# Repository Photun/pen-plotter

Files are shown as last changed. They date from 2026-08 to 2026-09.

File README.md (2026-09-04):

# CoreXY Pen Plotter

A large format Arduino based CoreXY pen plotter with a custom slicer app for turning digital artwork into physical drawings.

## Why This Exists

I intialliy built this beucase I got tired of having to hand trace digital drawings onto paper for art projects, and I wanted to build something that could not only accomodate large poster sizes but also do it with much more precision. So thats why I built this large CoreXY Plotter. I've seen a lot of plotters out there, but none are as big as what I've designed, nor are they as cheap as mine. Mine doens't use large expensive linear rails or flexible rods, but instead it uses rollers to utilize extrusions as the strong gantry while having customizeable sizes. It is mostly 3D printed parts or common hardware parts, no rare or expensive parts. It's rigidity allows it to draw even large desgisn with high precision and repeatability. It can accomodate both pen or pencil, so with more complex code it could probably imitate human handwriting, though obviously not 100%. The design is very human. 

## Photos And Demo

Main project photo:

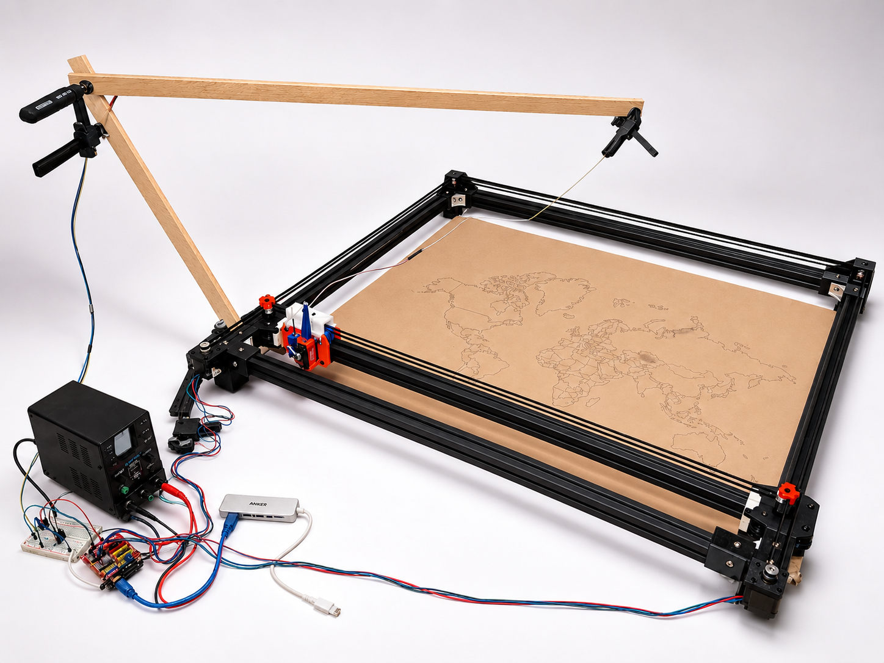
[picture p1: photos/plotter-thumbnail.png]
CoreXY pen plotter


Demo video:

[Plotter running demo video](photos/demo-plotter-running.mp4)

## What It Does

This project is meant to make large physical line drawings from normal digital
artwork without needing a commercial plotter or a bunch of expensive motion
hardware. The machine can be used on large poster sized paper, but can also be
configured to only draw on a mapped smaller size paper through the application.

The custom Plotter Studio app is the brain of the whole plotter. It allows you to import SVGs
or trace raster images, preview and adjust your drawing, then slice the plate into gcode
 and send it directly to the Arduino over USB. The device tab also replaces the usual pile of terminal commands with buttons for connection, manual homing, jogging, pen control, live
speed/accel tuning, job progress, and a small live job map.

The firmware is intentionally simple enough to run on an Arduino Uno, but still
handles the plotter's key features: CoreXY motor conversion, absolute gcode
movement, manual home confirmation, trapezoid style acceleration, task interjection,
servo pen up/down timing, and MOSFET controlled servo power to avoid the
boot twitch problem.

## How It Fits Together

The hardware is the large CoreXY frame, rollers, belts, gantry, and pen toolhead. 
The firmware is the real time layer that turns gcode into step pulses and pen movements. 
Plotter Studio is the computer side layer that turns art into motor instructions from user input.
The user imports art, fits it to the selected drawing area, generates gcode, provides the 
preview, and streams it to the Uno firmware.

## Build One

Start with the hardware docs:

- [Assembly guide](hardware/assembly.md)
- [Bill of materials](hardware/bom.md)
- Printable STL files in [hardware/exports/stl](hardware/exports/stl)
- Printable STEP files in [hardware/exports/step](hardware/exports/step)
- Full assembly STEP file in [hardware/exports/assembly](hardware/exports/assembly)

The CAD is also available in Onshape:

```text
https://cad.onshape.com/documents/21408afa0678dfc090a39137/w/cada99e8b20e026a88815622/e/614e2d6018b77ddf107765d2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
```

After the hardware is assembled and wired, use
[Plotter Studio instructions](firmware/instructions.md) to upload the Arduino
firmware, launch the app, run first motion tests, align letter paper, import art,
slice the plate, and send drawings. The deeper firmware/app notes are in
[firmware/technical-notes.md](firmware/technical-notes.md).

## Repo Layout

```text
hardware/            assembly guide, BOM, exported CAD/STL files
firmware/            Arduino firmware, Plotter Studio app, scripts, examples
photos/              sample plots, wiring photos, demo video
```

Most readers should start with this README, then `hardware/assembly.md`, then
`hardware/bom.md`. The firmware internals are mostly for people changing code.

Generated local folders such as `.pio/`, `.venv/`, `.plotter-app/`, and
`Plotter Studio.app/` are not part of the source package.

## What I Would Do Differently

The biggest thing I would rethink is tolerance. This project made it really
obvious that CAD numbers and printed numbers are not the same thing, especially
with ABS. Warping can change dimensions enough that one part is too tight while
another part is too loose, even when they were designed with the same logic. The
toolhead is a little loose in some places, and that costs rigidity, which then
costs drawing precision.

The rollers also showed this problem. Some spin smoothly, some are too tight,
and some basically drag instead of rolling. After seeing the actual prints, I
started wondering if a sliding plastic block in the extrusion groove might have
been better than round rollers. A roller only touches at a tangent point, while a
printed rectangular slider could contact the extrusion in a more constrained and
repeatable way. It might even be more precise, as long as the friction is
manageable.

The belt clamp mount is another place where I designed the part first and
thought about assembly second. It works, but it was one of the hardest parts to
put together. If I rebuilt it, I would probably design more of that toolhead area
as one piece instead of splitting it into pieces just to avoid supports. I did
not trust support structures that much while designing this, but after printing
more parts, I am a lot more willing to use supports for harder shapes if it makes
the final assembly simpler and stiffer.

## License

This project is licensed under the MIT License. See `LICENSE`.

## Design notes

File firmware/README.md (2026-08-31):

# Firmware And Plotter Studio

This folder contains the Arduino firmware, the Plotter Studio app, and the small
helper scripts used to run the machine.

Start here:

- [Instructions](instructions.md) for normal use: opening art,
  slicing, connecting, homing, tuning, and sending a plot.
- [Technical notes](technical-notes.md) for how the app, slicer, serial sender,
  gcode, motion planner, and servo power system fit together.

Most users should not need to touch the Python scripts directly. Normal drawing
happens through Plotter Studio, while firmware only needs to be re-uploaded when
`src/main.cpp` changes.

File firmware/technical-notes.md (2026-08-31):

# Technical Notes

This file describes how the software side works. It is not the main user guide;
it is here so the firmware, slicer, and serial behavior are easier to understand
or modify later.

## System Shape

The plotter has three main software pieces:

```text
src/main.cpp                 Arduino Uno firmware
tools/plotter_studio.py      local Python backend and serial controller
app/static/*                 Plotter Studio frontend
```

The Mac app in `desktop/macos/` is a small WebKit wrapper. It starts the Python
backend and loads the local Plotter Studio page. The generated `Plotter
Studio.app` is intentionally ignored by git because it is a local build artifact.

## Firmware Target

```text
board: Arduino Uno
shield: CNC Shield V3
drivers: DRV8825
baud: 115200
machine area: X406 Y370
```

Pin mapping:

```text
D2   CNC Shield X step = CoreXY motor A step
D3   CNC Shield Y step = CoreXY motor B step
D5   CNC Shield X dir  = CoreXY motor A dir
D6   CNC Shield Y dir  = CoreXY motor B dir
D8   CNC Shield enable, active LOW
D11  Z-limit signal -> servo power MOSFET gate
D12  SpnEn -> servo signal
```

The machine coordinates are internal plotter units, not real millimeters. That
is why the full area is `406 x 370`, while Letter paper is represented as `140 x
108.182` in the app.

## Serial Protocol

The firmware reads newline-terminated serial commands at `115200` baud. Most
commands reply with `ok` when complete or `error` when rejected. The Python
backend sends one command at a time and waits for the acknowledgement before
sending the next normal gcode line.

There is also a realtime abort byte so `Stop` can interrupt long moves without
waiting for the current line to finish. After aborting, the app lifts the pen,
returns to `X0 Y0` when home is confirmed, and resets job state.

Manual serial commands:

```text
?                 show help
h                 confirm current position as X0 Y0
p                 print position/settings
mon / moff        enable / disable motors
u / d             pen up / pen down
son / soff        servo power on / off
a 100             set servo angle directly
s 20              set raw step delay
accel 20000       set raw acceleration
```

Supported plot-style commands:

```text
G0 Xn Yn Fn       travel move
G1 Xn Yn Fn       draw move
G5 Xn Yn I J P Q  cubic bezier move
G28 P1            confirm manual home at X0 Y0
M3                pen down
M5                pen up
M17 / M18         motors on / off
M204 Snnn         acceleration in steps/sec^2
M340 U D L        pen up wait, pen down wait, lift percent
M2 / M30          end program, pen up and servo off
```

## Motion Planning

The firmware uses CoreXY mixing, so Cartesian X/Y moves are converted into motor
A/B step counts. The movement loop steps whichever motor axes need a pulse at
each Bresenham-like interval so straight lines stay coordinated.

Speed is controlled mainly by step delay. Lower delay means faster pulses.
Acceleration controls how quickly the firmware is allowed to approach that
requested speed. The intended velocity profile is trapezoidal: accelerate,
cruise when the line is long enough, then decelerate. For short moves, the
profile naturally becomes triangular because there is not enough distance to hit
the requested top speed.

Curves are not sent as hundreds of tiny straight gcode segments when the slicer
can preserve them. The app can emit cubic bezier moves as `G5`, and the firmware
samples those curves internally while sharing one continuous motion profile
across the curve. This avoids the repeated stop/start behavior that happens when
a curve is broken into too many independent line moves.

## Servo Power And Pen Lift

The pen servo is powered through a low-side MOSFET so it does not twitch at boot.
The firmware sets the desired servo target, attaches the servo signal, then turns
on the MOSFET-controlled power. When powering off, it lifts the pen first, cuts
power, waits briefly, then detaches the servo signal.

Wiring summary:

```text
Servo red wire       -> external 5V +
Servo brown/black    -> MOSFET drain
MOSFET source        -> external 5V GND and Arduino/CNC shield GND
Servo orange/yellow  -> CNC shield SpnEn / D12 signal
D11 / Z-limit signal -> 220 ohm resistor -> MOSFET gate
MOSFET gate          -> 10k pulldown -> GND
```

All grounds must be common.

The app exposes pen up wait, pen down wait, and pen up lift percent. The lift
percent is useful for dense dotted drawings where the pen only needs to rise a
little before the next nearby stroke.

## Slicing Pipeline

Plotter Studio accepts SVG directly and raster images through the trace importer.
SVG paths are parsed with `svgpathtools`. Lines, quadratic curves, cubic curves,
and arcs are normalized into drawable strokes. The slicer keeps cubic geometry
where possible so the firmware can run smoother bezier motion.

Raster tracing uses OpenCV-based preprocessing and contour extraction. The import
settings control how aggressively edges are found, simplified, linked, and
filtered. Tracing runs as a cancellable job: changing a setting abandons the old
trace request so a bad threshold does not trap the app in a long computation.

Before gcode is accepted, the backend checks machine bounds, selected paper
bounds, and margin warnings. Outside the machine or selected paper blocks
slicing. Inside the paper margin only warns.

After slicing, the generated preview contains path geometry, gcode text, bounds,
warnings, estimated distance, and estimated runtime. Confirming the slice queues
that result for the Device tab.

## Route Optimization

The slicer groups drawable geometry into strokes and orders them to reduce
pen-up travel. It can reverse strokes when starting from the other end is
shorter. This is a practical nearest-neighbor style optimization, not a perfect
traveling-salesman solve. The goal is to cut obvious wasted travel without
making slicing painfully slow.

This matters because every pen-up travel and every separate stroke resets some
motion momentum. Fewer disconnected strokes usually means less servo waiting,
less acceleration/deceleration, and a cleaner plot.

## Generated And Ignored Files

These are local artifacts and should not be committed:

```text
.pio/
.venv/
.plotter-app/
Plotter Studio.app/
```

The source files live in git. The built app, Python environment, PlatformIO
builds, uploaded images, and local logs are regenerated on each machine.

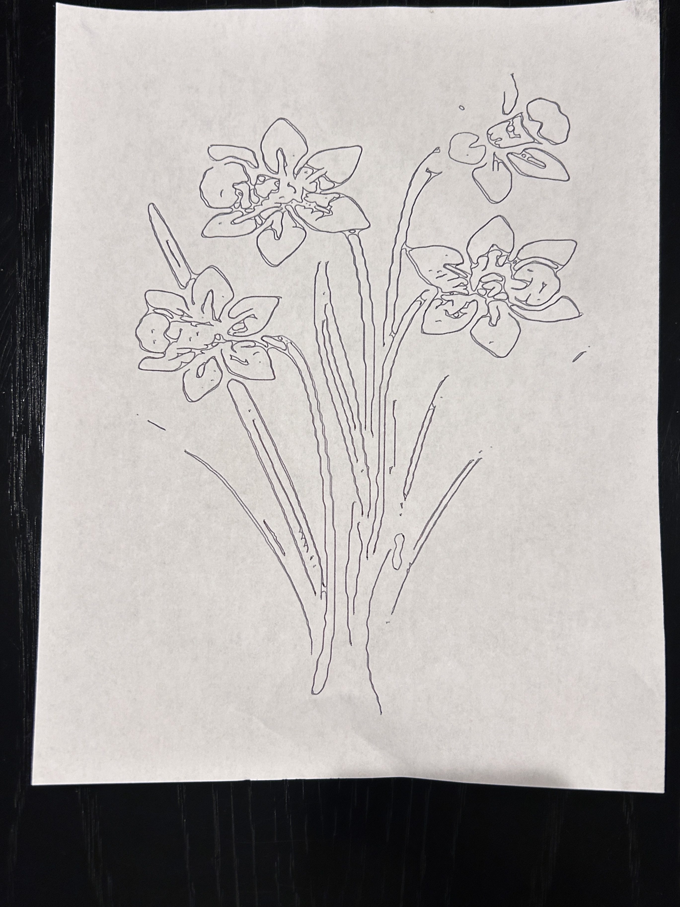
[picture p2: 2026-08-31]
photos/sample-plot-flowers.jpg

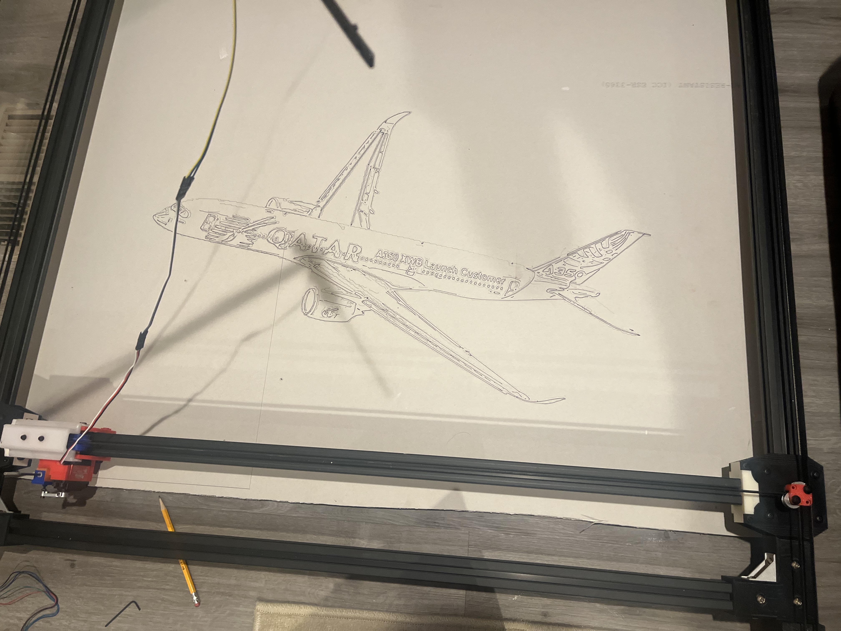
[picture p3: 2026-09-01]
photos/sample-plot-airplane.jpg

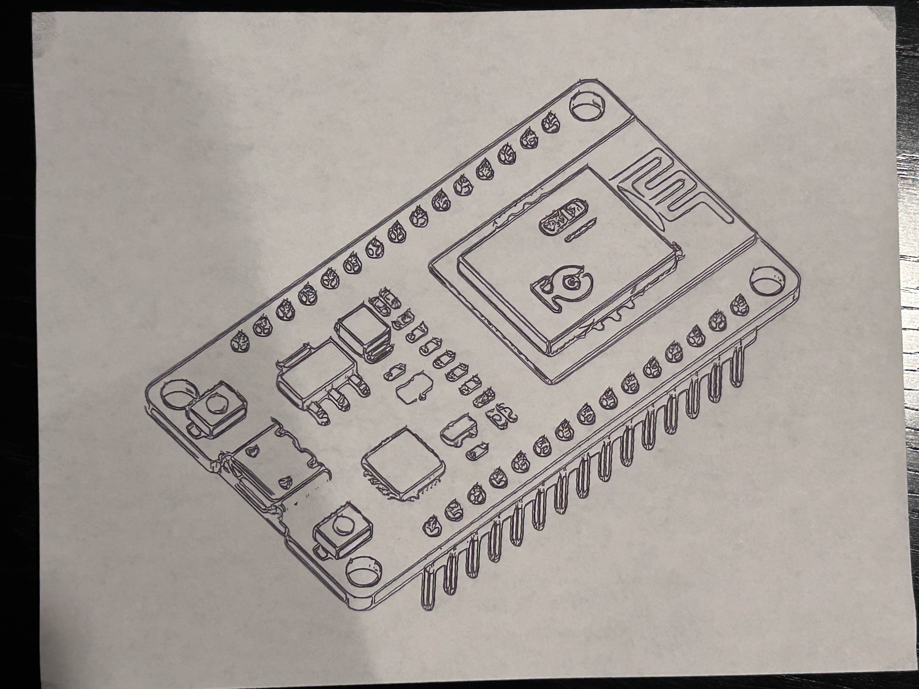
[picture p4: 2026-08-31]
photos/sample-plot-esp32-board.jpg

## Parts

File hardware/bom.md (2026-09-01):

# Bill of Materials

This BOM is split into purchase groups and itemized build parts. Some rows in
the machine are bought together, so the price belongs to the kit/link, not every
individual part inside it.

Prices are pulled from the linked listings when available, but should still be
checked before ordering because Amazon prices move around.

## Purchase Groups

| ID | Buy / source | Price | Notes |
| --- | --- | ---: | --- |
| P01 | [DAOKI CNC Shield V3.0 kit](https://www.amazon.com/dp/B08KFYKKN4) | $9.99 | Includes Arduino-compatible Uno, CNC Shield V3, 4 DRV8825 drivers, heatsinks, jumper caps, and USB cable. |
| P02 | [STEPPERONLINE NEMA 17 stepper motor, 3-pack](https://www.amazon.com/dp/B0B38GHRH8) | $10.19 | Build uses 2 motors; this listing includes 3. |
| P03 | [ANNIMOS 20kg metal gear servo](https://www.amazon.com/dp/B0769DFJVK) | $14.99 | Pen lift servo. |
| P04 | [GT2 belt, pulley, idler, tensioner, and clamp kit](https://www.amazon.com/dp/B0D2XXF6H7) | $14.99 each | Buy 2. Each kit has 5m of 6mm GT2 belt, 20T pulleys, idlers, tensioner springs, clamp blocks, and wrench. |
| P05 | [uxcell 625ZZ bearings, 25-pack](https://www.amazon.com/dp/B0CJFRSK7D) | $7.89 | Build uses 24 bearings. |
| P06 | [3030 aluminum extrusion, 39.4 inch, 10-pack](https://www.amazon.com/dp/B0C9WGJNR9) | $46.99 | Cut into the frame and gantry pieces. |
| P07 | [3030 corner bracket + M6 T-nut connector kit](https://www.amazon.com/dp/B0B12FJRQ3) | Check listing | Includes 3030 corner brackets, M6 T-nuts, M6 x 12 bolts, and wrench. |
| P08 | [M3 screw/nut/washer assortment](https://www.amazon.com/dp/B0FGV5FCBN) | $9.99 | Small toolhead, cart, servo, and motor hardware. |
| P09 | [M4 screw/nut/washer assortment](https://www.amazon.com/dp/B0DD79T1CW) | $9.99 | Belt clamp hardware. |
| P10 | [M5 screw/nut/washer assortment](https://www.amazon.com/dp/B0CSY7FMQD) | $9.99 | Roller and pulley stack hardware. |
| P11 | [M6 screw/nut/washer assortment](https://www.amazon.com/dp/B0GHM7GBXF) | $9.99 | Optional/extra M6 hardware. The connector kit already includes the main M6 x 12 frame bolts. |
| P12 | [IRLZ44N logic-level N-channel MOSFET](https://www.amazon.com/IRLZ44N-IRLZ44NPBF-Mosfet-N-Channel-0-02Ohm/dp/B09SV14RX7) | Check listing | Servo anti-twitch power switch. |
| P13 | [Aluminum cutting blade and paraffin wax](https://www.amazon.com/s?k=aluminum+cutting+blade+paraffin+wax) | Check listing | Optional extrusion cutting helpers. |
| A01 | Assumed project supplies | Already owned | Breadboard, 220 ohm resistor, 10k ohm resistor, bench power supply, external 5V source, pen/pencil, spring, zip tie, and jumper wires. |

## Itemized Purchased Parts

| Part | Qty. used | Source group | Notes |
| --- | ---: | --- | --- |
| Arduino Uno-compatible board | 1 | P01 | Included in the electronics kit. |
| CNC Shield V3 | 1 | P01 | Plugs into the Uno. |
| DRV8825 motor driver | 2 | P01 | Kit includes 4; this build uses 2. Set current limit to about 0.45-0.5A. |
| Arduino USB cable | 1 | P01 | Included in the electronics kit. |
| 20kg servo | 1 | P03 | Pen lift servo. |
| Servo horn | 1 | P03 | Use the servo's included horn. |
| NEMA 17 stepper motor | 2 | P02 | CoreXY motor A and motor B. |
| GT2 timing belt | 2x 5m | P04 | Buy 2 kits so each motor gets its own 5m belt. |
| GT2 20T drive pulley, 6mm belt width | 2 | P04 | Mounted to the two stepper shafts. |
| GT2 idler pulley | 8 | P04 | Build uses 6 toothed-style idlers and 2 toothless/smooth-style idlers. Confirm the exact pulley style in the kit before ordering. |
| GT2 aluminum timing belt clamp | 2 | P04 | Included with the GT2 kit. Mounted to the printed belt clamp mount. |
| 625 bearing | 24 | P05 | Used in rollers and bearing stacks. |
| 3030 aluminum extrusion, length pieces | 2 | P06 | 1m pieces before cutting. |
| 3030 aluminum extrusion, width pieces | 2 | P06 | 1m pieces before cutting. |
| 3030 aluminum extrusion, gantry piece | 1 | P06 | Cut from extrusion stock. Use the gantry jig or cut off 58.2mm. |
| 3030 T-nut | 30 | P07 | Use one with each M6 x 12 frame bolt. Gantry extrusion mount ones are optional and not counted. |
| Extrusion bracket | 4 | P07 | Metal brackets for frame corners. |
| M6 x 12 bolt | 30 | P07 | Used wherever a T-nut is used. |
| M6 x 30 bolt | 4 | P11 | Optional if additional gantry-to-cart T-nuts are not desired. |
| M6 washer | 4 | P11 | Optional, used with M6 x 30. |
| M5 x 45 bolt | 8 | P10 | Back corner brackets, bottom of toolhead cart, and Y-cart pulleys. |
| M5 x 50 bolt | 10 | P10 | Y-cart rollers and upper rollers of the toolhead. |
| M5 nut | 18 | P10 | On cart bottoms and roller stacks. |
| M5 washer | 18 | P10 | Used with M5 roller hardware. |
| M4 x 12 bolt | 2 | P09 | Secures belt clamp onto belt clamp mount. |
| M4 nut | 2 | P09 | Behind belt clamp mount. |
| M4 washer | 2 | P09 | Behind belt clamp. |
| M3 x 6 bolt | 1 | P08 | Pencil block pencil clamp. |
| M3 x 10 bolt | 10 | P08 | Stepper motors and belt clamp mount. |
| M3 x 16 bolt | 9 | P08 | Servo/toolhead hardware; 8 rigidity screws are optional. |
| M3 x 25 bolt | 4 | P08 | Y carts for securing upper mold. Optional. |
| M3 nut | 4 | P08 | Two embedded in belt mount, two on M3 x 16 servo mount. |
| M3 washer | 18 | P08 | Small fastener washers. |
| Breadboard | 1 | A01 | Easier interface for servo/MOSFET wiring. |
| Jumper wires | about 40 M-F, about 3 M-M | A01 | Servo power circuit and CNC shield to breadboard wiring. Mostly long male-to-female wires. |
| IRLZ44N logic-level N-channel MOSFET | 1 | P12 | Switches servo ground/power to prevent boot twitch. Logic-level equivalent is okay. |
| 220 ohm resistor | 1 | A01 | Between D11/Z-limit signal and MOSFET gate. |
| 10k ohm resistor | 1 | A01 | Gate pulldown to ground. |
| External 5V power source | 1 | A01 | Powers servo through breadboard rails. |
| 12V bench power supply | 1 | A01 | Powers the CNC shield/motors. Set current low at first during testing. |
| Pen or pencil | 1 | A01 | For pens, remove the ink cartridge and use the pen adapter. |
| Spring for pencil mount | 1 | A01 | OD less than 12mm, height around 30mm. |
| Zip tie | 1 | A01 | 4 inch zip tie for securing servo wire onto aligner. |
| Aluminum cutting blade | optional | P13 | Optional, cleaner extrusion cuts. Prefer negative-angle TCG for nonferrous aluminum. |
| Paraffin wax block | optional | P13 | Optional cutting helper for extrusion. |

## Printed Parts

These parts require PLA, ABS, and PETG filament. The table lists the material
for each part, but no specific filament brand is required.

| Part | Qty. | Material | STL | STEP |
| --- | ---: | --- | --- | --- |
| 0.5 mm Spacer for Y Cart | 2 | PLA | [STL](exports/stl/0.5-mm-Spacer-for-Y-Cart.stl) | [STEP](exports/step/0.5-mm-Spacer-for-Y-Cart.step) |
| 1 mm Spacer for Y Cart | 6 | PLA | [STL](exports/stl/1-mm-Spacer-for-Y-Cart.stl) | [STEP](exports/step/1-mm-Spacer-for-Y-Cart.step) |
| 1.5 mm M+U Spacer for Corner Brackets | 4 | PLA | [STL](exports/stl/1.5-mm-M-U-Spacer-for-Corner-Brackets.stl) | [STEP](exports/step/1.5-mm-M+U-Spacer-for-Corner-Brackets.step) |
| 7.25 mm L Spacer for Corner Brackets | 2 | PLA | [STL](exports/stl/7.25-mm-L-Spacer-for-Corner-Brackets.stl) | [STEP](exports/step/7.25-mm-L-Spacer-for-Corner-Brackets.step) |
| Back Corner Brackets | 2 | ABS | [STL](exports/stl/Back-Corner-Brackets.stl) | [STEP](exports/step/Back-Corner-Brackets.step) |
| Bearing-to-Bearing Internal Roller Spacer | 12 | PLA | [STL](exports/stl/Bearing-to-Bearing-Internal-Roller-Spacer.stl) | [STEP](exports/step/Bearing-to-Bearing-Internal-Roller-Spacer.step) |
| Belt Clamp Mount | 1 | ABS | [STL](exports/stl/Belt-Clamp-Mount.stl) | [STEP](exports/step/Belt-Clamp-Mount.step) |
| Cart Cart Plate | 2 | ABS | [STL](exports/stl/Cart-Cart-Plate.stl) | [STEP](exports/step/Cart-Cart-Plate.step) |
| Cart-to-Bearing Spacer | 24 | PLA | [STL](exports/stl/Cart-to-Bearing-Spacer.stl) | [STEP](exports/step/Cart-to-Bearing-Spacer.step) |
| Gantry Extrusion Jig | 1 | PLA | [STL](exports/stl/Gantry-Extrusion-Jig.stl) | [STEP](exports/step/Gantry-Extrusion-Jig.step) |
| Left Corner Bracket | 1 | ABS | [STL](exports/stl/Left-Corner-Bracket.stl) | [STEP](exports/step/Left-Corner-Bracket.step) |
| Left Lower Cart Plate | 1 | ABS | [STL](exports/stl/Left-Lower-Cart-Plate.stl) | [STEP](exports/step/Left-Lower-Cart-Plate.step) |
| Left Upper Cart Plate | 1 | ABS | [STL](exports/stl/Left-Upper-Cart-Plate.stl) | [STEP](exports/step/Left-Upper-Cart-Plate.step) |
| Left Upper Cart Upper Mold | 1 | ABS | [STL](exports/stl/Left-Upper-Cart-Upper-Mold.stl) | [STEP](exports/step/Left-Upper-Cart-Upper-Mold.step) |
| Modified Surface Roller | 2 | PLA | [STL](exports/stl/Modified-Surface-Roller.stl) | [STEP](exports/step/Modified-Surface-Roller.step) |
| Pen Adapter | optional | PETG | [STL](exports/stl/Pen-Adapter.stl) | [STEP](exports/step/Pen-Adapter.step) |
| Pencil Block | 1 | PLA | [STL](exports/stl/Pencil-Block.stl) | [STEP](exports/step/Pencil-Block.step) |
| Pencil Housing | 1 | PLA | [STL](exports/stl/Pencil-Housing.stl) | [STEP](exports/step/Pencil-Housing.step) |
| Pencil Housing Cap | 1 | PLA | [STL](exports/stl/Pencil-Housing-Cap.stl) | [STEP](exports/step/Pencil-Housing-Cap.step) |
| Right Corner Bracket | 1 | ABS | [STL](exports/stl/Right-Corner-Bracket.stl) | [STEP](exports/step/Right-Corner-Bracket.step) |
| Right Lower Cart Bottom | 1 | ABS | [STL](exports/stl/Right-lower-Cart-Bottom.stl) | [STEP](exports/step/Right-Lower-Cart-Bottom.step) |
| Right Upper Cart Plate | 1 | ABS | [STL](exports/stl/Right-Upper-Cart-Plate.stl) | [STEP](exports/step/Right-Upper-Cart-Plate.step) |
| Right Upper Cart Upper Mold | 1 | ABS | [STL](exports/stl/Right-Upper-Cart-Upper-Mold.stl) | [STEP](exports/step/Right-Upper-Cart-Upper-Mold.step) |
| Servo Wire Aligner | 1 | PLA | [STL](exports/stl/Servo-Wire-Aligner.stl) | [STEP](exports/step/Servo-Wire-Aligner.step) |
| Stepper to Drive Pulley Spacer | 2 | PLA | [STL](exports/stl/Stepper-to-Drive-Pulley-Spacer.stl) | [STEP](exports/step/Stepper-to-Drive-Pulley-Spacer.step) |
| Surface Roller | 10 | ABS | [STL](exports/stl/Surface-Roller.stl) | [STEP](exports/step/Surface-Roller.step) |
| Toolhead Cart Back | 1 | ABS | [STL](exports/stl/Toolhead-Cart-Back.stl) | [STEP](exports/step/Toolhead-Cart-Back.step) |
| Toolhead Cart Connector | 1 | PETG | [STL](exports/stl/Toolhead-Cart-connector.stl) | [STEP](exports/step/Toolhead-Cart-Connector.step) |
| Toolhead Front Cart | 1 | ABS | [STL](exports/stl/Toolhead-Front-Cart.stl) | [STEP](exports/step/Toolhead-Front-Cart.step) |

## Cost Notes

The purchase-group total is only a rough build estimate because many links are
kits, leftovers, or optional tools. If someone already has filament, fasteners,
a power supply, jumper wires, or cutting tools, the real extra cost will be much
lower than buying every source group from scratch.

Using the listed Amazon prices for the main required purchase groups, the build
lands around **$180-$260 USD** if the builder already has common project
supplies like wire, resistors, breadboard, power supplies, basic tools, and
filament. Buying every support item from scratch can push the practical total
closer to **$230-$350 USD**, depending on the exact connector kit, MOSFET pack,
filament rolls, cutting tools, and what hardware assortments the builder already
owns.

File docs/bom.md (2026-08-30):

# Bill of Materials

This is the readable copy of `docs/bom.csv`. The CSV is the spreadsheet-friendly source, and this page is for quickly checking the parts list in the repo.

| Name | Quantity | Material | Description |
| --- | ---: | --- | --- |
| 0.5 mm Spacer for Y Cart | 2 | PLA | Goes on top of the lower pulley on Y carts. |
| 1 mm Spacer for Y Cart | 6 | PLA | Under lower pulley, above and below for upper pulley, on Y cart. |
| 1.5 mm M+U Spacer for Corner Brackets | 4 | PLA | Spacer for the back corner bracket mounts, goes above both idler pulleys. |
| 20kg Servo | 1 | - | - |
| 3030 T nut | 30 | - | Use one with every M6 x 12 nut. Gantry extrusion mount ones are optional. (not counted) |
| 625 Bearing | 24 | - | - |
| 7.25 mm L Spacer for Corner Brackets | 2 | PLA | Bottommost object in the back bracket pulley stack. |
| Aluminum Cutting Blade | - | - | Optional, ideal for cleaner extrusion cuts. Preferably negative angle TCG for nonferrous materials. |
| Arduino Uno + CNC Shield | 1 | - | - |
| Arduino USB cable | 1 | - | - |
| Back Corner Brackets | 2 | ABS | Same for both far side corners. |
| Bearing-to-Bearing Internal Roller Spacer | 12 | PLA | Sandwhiched by bearings inside surface rollers. |
| Belt Clamp Mount | 1 | ABS | Be careful of over tightening the M4 screws onto this. |
| Breadboard | 1 | - | Easier interface for wiring servo. |
| Cart Cart Plate | 2 | ABS | M3x10-16 work for rigidity screws. |
| Cart-to-Bearing Spacer | 24 | PLA | Outside of 625 bearings. |
| Drive Pulley | 2 | - | 6mm GT2 |
| DRV8825 Motor Driver | 2 | - | Set max current to about 0.45 - 0.5. |
| External 5v power source | 1 | - | Plug into rails of breadboard, to power servo. Wiring guide provided. |
| Extrusion Brackets | 4 | - | - |
| Gantry Extrusion | 1 | - | Use gantry jig to cut precisely. Better to cut shorter than leave extra. |
| Gantry Extrusion Jig | 1 | PLA | Optional, or just cut off 58.2 mm |
| GT2 Aluminum Timing Belt Clamp | 2 | - | To be purchased. |
| GT2 Timing Belt | 2x5m | - | One for each motor. |
| IRFZ44N | 1 | - | For preventing servo startup twitch. Wiring guide provided. |
| Jumper Wires | - | - | For cable to servo and some CNC sheild to breadboard wiring. |
| Left Corner Bracket | 1 | ABS | - |
| Left Lower Cart Plate | 1 | ABS | - |
| Left Upper Cart Plate | 1 | ABS | - |
| Left Upper Cart Upper Mold | 1 | ABS | - |
| Length Extrusion | 2 | - | 1 meter |
| M3 nut | 4 | - | 2 more embedded in the belt mount, and 2 on the M3 x 16 on the servo to keep it in place. |
| M3 washer | 18 | - | - |
| M3 x 10 | 10 | - | Holding stepper motors and belt clamp mount onto overarching toolhead block thingy. |
| M3 x 16 | 9 | - | 8 for rigidity are optional. |
| M3 x 25 | 4 | - | On y carts for securing upper mold. *Optional - probably not needded.* |
| M3 x 6 | 1 | - | On pencil block for holding pencil. |
| M4 nut | 2 | - | Behind belt clamp mount |
| M4 washer | 2 | - | Behind belt clamp |
| M4 x 12 | 2 | - | For securing belt clamp onto its mount. |
| M5 nut | 18 | - | On cart bottoms |
| M5 washer | 18 | - | - |
| M5 x 45 | 8 | - | Back corner brackets, bottom of toolhead cart, pulleys of Y carts. |
| M5 x 50 | 10 | - | Roller of Y carts, upper rollers of toolhead. |
| M6 washer | 4 | - | Optional - with the M6 x 30 |
| M6 x 12 | 30 | - | Wherever a T nut is used. |
| M6 x 30 | 4 | - | Optional if additional gantry to cart-cart-plate T nut is not desired. |
| Modified Surface Roller | 2 | PLA | Allows belt to pass through with 0.25 mm clearance. |
| Parrafin Wax Block | - | - | Optional, assists with clean extrusion cuts |
| Pen Adapter | - | PETG | Optional, if using pen. |
| Pen/Pencil | 1 | - | For pens, take out the pen itself from a pen and print the pen adapter to use. |
| Pencil Block | 1 | PLA | - |
| Pencil Housing | 1 | PLA | - |
| Pencil Housing Cap | 1 | PLA | Put spring in before putting on the cap. |
| Power Bench | - | - | 12 volts, 1 amp for everything. Plut into CNC shield's input terminal. |
| Right Corner Bracket | 1 | ABS | - |
| Right lower Cart Bottom | 1 | ABS | - |
| Right Upper Cart Plate | 1 | ABS | - |
| Right Upper Cart Upper Mold | 1 | ABS | - |
| Servo Horn | 1 | - | Use OEM's. |
| Servo Wire Aligner | 1 | PLA | To ensure wire does not wrap or tangle during movement. |
| Spring for Pencil Mount | 1 | - | OD less than 12mm, height around 30mm. |
| Stepper Motor | 2 | - | Nema 17 |
| Stepper to Drive Pulley Spacer | 2 | PLA | On stepper axle, between the motor and the drive pulley. |
| Surface Roller | 10 | ABS | - |
| Toolhead Cart Back | 1 | ABS | - |
| Toolhead Cart connector | 1 | PETG | - |
| Toolhead Front Cart | 1 | ABS | - |
| Toothed Idler Pulley | 6 | - | - |
| Toothless Idler Pulley | 2 | - | For first reverse wind of belt from motor. |
| Width Extrusion | 2 | - | 1 meter |
| Zip Tie | 1 | - | 4" zip ties, for securing servo wire onto aligner. |

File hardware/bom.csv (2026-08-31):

type | id | name | quantity | source_group | price | material | notes | product_link | stl_link | step_link
purchase_group | P01 | DAOKI CNC Shield V3.0 kit |  |  | $9.99 |  | Includes Arduino-compatible Uno, CNC Shield V3, 4 DRV8825 drivers, heatsinks, jumper caps, and USB cable. | https://www.amazon.com/dp/B08KFYKKN4
purchase_group | P02 | STEPPERONLINE NEMA 17 stepper motor, 3-pack |  |  | $10.19 |  | Build uses 2 motors; this listing includes 3. | https://www.amazon.com/dp/B0B38GHRH8
purchase_group | P03 | ANNIMOS 20kg metal gear servo |  |  | $14.99 |  | Pen lift servo. | https://www.amazon.com/dp/B0769DFJVK
purchase_group | P04 | GT2 belt, pulley, idler, tensioner, and clamp kit |  |  | $14.99 each |  | Buy 2. Each kit has 5m of 6mm GT2 belt, 20T pulleys, idlers, tensioner springs, clamp blocks, and wrench. | https://www.amazon.com/dp/B0D2XXF6H7
purchase_group | P05 | uxcell 625ZZ bearings, 25-pack |  |  | $7.89 |  | Build uses 24 bearings. | https://www.amazon.com/dp/B0CJFRSK7D
purchase_group | P06 | 3030 aluminum extrusion, 39.4 inch, 10-pack |  |  | $46.99 |  | Cut into the frame and gantry pieces. | https://www.amazon.com/dp/B0C9WGJNR9
purchase_group | P07 | 3030 corner bracket + M6 T-nut connector kit |  |  | Check listing |  | Includes 3030 corner brackets, M6 T-nuts, M6 x 12 bolts, and wrench. | https://www.amazon.com/dp/B0B12FJRQ3
purchase_group | P08 | M3 screw/nut/washer assortment |  |  | $9.99 |  | Small toolhead, cart, servo, and motor hardware. | https://www.amazon.com/dp/B0FGV5FCBN
purchase_group | P09 | M4 screw/nut/washer assortment |  |  | $9.99 |  | Belt clamp hardware. | https://www.amazon.com/dp/B0DD79T1CW
purchase_group | P10 | M5 screw/nut/washer assortment |  |  | $9.99 |  | Roller and pulley stack hardware. | https://www.amazon.com/dp/B0CSY7FMQD
purchase_group | P11 | M6 screw/nut/washer assortment |  |  | $9.99 |  | Optional/extra M6 hardware. The connector kit already includes the main M6 x 12 frame bolts. | https://www.amazon.com/dp/B0GHM7GBXF
purchase_group | P12 | IRLZ44N logic-level N-channel MOSFET |  |  | Check listing |  | Servo anti-twitch power switch. | https://www.amazon.com/IRLZ44N-IRLZ44NPBF-Mosfet-N-Channel-0-02Ohm/dp/B09SV14RX7
purchase_group | P13 | Aluminum cutting blade and paraffin wax |  |  | Check listing |  | Optional extrusion cutting helpers. | https://www.amazon.com/s?k=aluminum+cutting+blade+paraffin+wax
purchase_group | A01 | Assumed project supplies |  |  | Already owned |  | Breadboard, 220 ohm resistor, 10k ohm resistor, bench power supply, external 5V source, pen/pencil, spring, zip tie, and jumper wires.
itemized_part |  | Arduino Uno-compatible board | 1 | P01 |  |  | Included in the electronics kit.
itemized_part |  | CNC Shield V3 | 1 | P01 |  |  | Plugs into the Uno.
itemized_part |  | DRV8825 motor driver | 2 | P01 |  |  | Kit includes 4; this build uses 2. Set current limit to about 0.45-0.5A.
itemized_part |  | Arduino USB cable | 1 | P01 |  |  | Included in the electronics kit.
itemized_part |  | 20kg servo | 1 | P03 |  |  | Pen lift servo.
itemized_part |  | Servo horn | 1 | P03 |  |  | Use the servo's included horn.
itemized_part |  | NEMA 17 stepper motor | 2 | P02 |  |  | CoreXY motor A and motor B.
itemized_part |  | GT2 timing belt | 2x 5m | P04 |  |  | Buy 2 kits so each motor gets its own 5m belt.
itemized_part |  | GT2 20T drive pulley, 6mm belt width | 2 | P04 |  |  | Mounted to the two stepper shafts.
itemized_part |  | GT2 idler pulley | 8 | P04 |  |  | Build uses 6 toothed-style idlers and 2 toothless/smooth-style idlers. Confirm the exact pulley style in the kit before ordering.
itemized_part |  | GT2 aluminum timing belt clamp | 2 | P04 |  |  | Included with the GT2 kit. Mounted to the printed belt clamp mount.
itemized_part |  | 625 bearing | 24 | P05 |  |  | Used in rollers and bearing stacks.
itemized_part |  | 3030 aluminum extrusion, length pieces | 2 | P06 |  |  | 1m pieces before cutting.
itemized_part |  | 3030 aluminum extrusion, width pieces | 2 | P06 |  |  | 1m pieces before cutting.
itemized_part |  | 3030 aluminum extrusion, gantry piece | 1 | P06 |  |  | Cut from extrusion stock. Use the gantry jig or cut off 58.2mm.
itemized_part |  | 3030 T-nut | 30 | P07 |  |  | Use one with each M6 x 12 frame bolt. Gantry extrusion mount ones are optional and not counted.
itemized_part |  | Extrusion bracket | 4 | P07 |  |  | Metal brackets for frame corners.
itemized_part |  | M6 x 12 bolt | 30 | P07 |  |  | Used wherever a T-nut is used.
itemized_part |  | M6 x 30 bolt | 4 | P11 |  |  | Optional if additional gantry-to-cart T-nuts are not desired.
itemized_part |  | M6 washer | 4 | P11 |  |  | Optional, used with M6 x 30.
itemized_part |  | M5 x 45 bolt | 8 | P10 |  |  | Back corner brackets, bottom of toolhead cart, and Y-cart pulleys.
itemized_part |  | M5 x 50 bolt | 10 | P10 |  |  | Y-cart rollers and upper rollers of the toolhead.
itemized_part |  | M5 nut | 18 | P10 |  |  | On cart bottoms and roller stacks.
itemized_part |  | M5 washer | 18 | P10 |  |  | Used with M5 roller hardware.
itemized_part |  | M4 x 12 bolt | 2 | P09 |  |  | Secures belt clamp onto belt clamp mount.
itemized_part |  | M4 nut | 2 | P09 |  |  | Behind belt clamp mount.
itemized_part |  | M4 washer | 2 | P09 |  |  | Behind belt clamp.
itemized_part |  | M3 x 6 bolt | 1 | P08 |  |  | Pencil block pencil clamp.
itemized_part |  | M3 x 10 bolt | 10 | P08 |  |  | Stepper motors and belt clamp mount.
itemized_part |  | M3 x 16 bolt | 9 | P08 |  |  | Servo/toolhead hardware; 8 rigidity screws are optional.
itemized_part |  | M3 x 25 bolt | 4 | P08 |  |  | Y carts for securing upper mold. Optional.
itemized_part |  | M3 nut | 4 | P08 |  |  | Two embedded in belt mount, two on M3 x 16 servo mount.
itemized_part |  | M3 washer | 18 | P08 |  |  | Small fastener washers.
itemized_part |  | Breadboard | 1 | A01 |  |  | Easier interface for servo/MOSFET wiring.
itemized_part |  | Jumper wires | about 40 M-F, about 3 M-M | A01 |  |  | Servo power circuit and CNC shield to breadboard wiring. Mostly long male-to-female wires.
itemized_part |  | IRLZ44N logic-level N-channel MOSFET | 1 | P12 |  |  | Switches servo ground/power to prevent boot twitch. Logic-level equivalent is okay.
itemized_part |  | 220 ohm resistor | 1 | A01 |  |  | Between D11/Z-limit signal and MOSFET gate.
itemized_part |  | 10k ohm resistor | 1 | A01 |  |  | Gate pulldown to ground.
itemized_part |  | External 5V power source | 1 | A01 |  |  | Powers servo through breadboard rails.
itemized_part |  | 12V bench power supply | 1 | A01 |  |  | Powers the CNC shield/motors. Set current low at first during testing.
itemized_part |  | Pen or pencil | 1 | A01 |  |  | For pens, remove the ink cartridge and use the pen adapter.
itemized_part |  | Spring for pencil mount | 1 | A01 |  |  | OD less than 12mm, height around 30mm.
itemized_part |  | Zip tie | 1 | A01 |  |  | 4 inch zip tie for securing servo wire onto aligner.
itemized_part |  | Aluminum cutting blade | optional | P13 |  |  | Optional, cleaner extrusion cuts. Prefer negative-angle TCG for nonferrous aluminum.
itemized_part |  | Paraffin wax block | optional | P13 |  |  | Optional cutting helper for extrusion.
printed_part |  | 0.5 mm Spacer for Y Cart | 2 |  |  | PLA |  |  | exports/stl/0.5-mm-Spacer-for-Y-Cart.stl | exports/step/0.5-mm-Spacer-for-Y-Cart.step
printed_part |  | 1 mm Spacer for Y Cart | 6 |  |  | PLA |  |  | exports/stl/1-mm-Spacer-for-Y-Cart.stl | exports/step/1-mm-Spacer-for-Y-Cart.step
printed_part |  | 1.5 mm M+U Spacer for Corner Brackets | 4 |  |  | PLA |  |  | exports/stl/1.5-mm-M-U-Spacer-for-Corner-Brackets.stl | exports/step/1.5-mm-M+U-Spacer-for-Corner-Brackets.step
printed_part |  | 7.25 mm L Spacer for Corner Brackets | 2 |  |  | PLA |  |  | exports/stl/7.25-mm-L-Spacer-for-Corner-Brackets.stl | exports/step/7.25-mm-L-Spacer-for-Corner-Brackets.step
printed_part |  | Back Corner Brackets | 2 |  |  | ABS |  |  | exports/stl/Back-Corner-Brackets.stl | exports/step/Back-Corner-Brackets.step
printed_part |  | Bearing-to-Bearing Internal Roller Spacer | 12 |  |  | PLA |  |  | exports/stl/Bearing-to-Bearing-Internal-Roller-Spacer.stl | exports/step/Bearing-to-Bearing-Internal-Roller-Spacer.step
printed_part |  | Belt Clamp Mount | 1 |  |  | ABS |  |  | exports/stl/Belt-Clamp-Mount.stl | exports/step/Belt-Clamp-Mount.step
printed_part |  | Cart Cart Plate | 2 |  |  | ABS |  |  | exports/stl/Cart-Cart-Plate.stl | exports/step/Cart-Cart-Plate.step
printed_part |  | Cart-to-Bearing Spacer | 24 |  |  | PLA |  |  | exports/stl/Cart-to-Bearing-Spacer.stl | exports/step/Cart-to-Bearing-Spacer.step
printed_part |  | Gantry Extrusion Jig | 1 |  |  | PLA |  |  | exports/stl/Gantry-Extrusion-Jig.stl | exports/step/Gantry-Extrusion-Jig.step
printed_part |  | Left Corner Bracket | 1 |  |  | ABS |  |  | exports/stl/Left-Corner-Bracket.stl | exports/step/Left-Corner-Bracket.step
printed_part |  | Left Lower Cart Plate | 1 |  |  | ABS |  |  | exports/stl/Left-Lower-Cart-Plate.stl | exports/step/Left-Lower-Cart-Plate.step
printed_part |  | Left Upper Cart Plate | 1 |  |  | ABS |  |  | exports/stl/Left-Upper-Cart-Plate.stl | exports/step/Left-Upper-Cart-Plate.step
printed_part |  | Left Upper Cart Upper Mold | 1 |  |  | ABS |  |  | exports/stl/Left-Upper-Cart-Upper-Mold.stl | exports/step/Left-Upper-Cart-Upper-Mold.step
printed_part |  | Modified Surface Roller | 2 |  |  | PLA |  |  | exports/stl/Modified-Surface-Roller.stl | exports/step/Modified-Surface-Roller.step
printed_part |  | Pen Adapter | optional |  |  | PETG |  |  | exports/stl/Pen-Adapter.stl | exports/step/Pen-Adapter.step
printed_part |  | Pencil Block | 1 |  |  | PLA |  |  | exports/stl/Pencil-Block.stl | exports/step/Pencil-Block.step
printed_part |  | Pencil Housing | 1 |  |  | PLA |  |  | exports/stl/Pencil-Housing.stl | exports/step/Pencil-Housing.step
printed_part |  | Pencil Housing Cap | 1 |  |  | PLA |  |  | exports/stl/Pencil-Housing-Cap.stl | exports/step/Pencil-Housing-Cap.step
printed_part |  | Right Corner Bracket | 1 |  |  | ABS |  |  | exports/stl/Right-Corner-Bracket.stl | exports/step/Right-Corner-Bracket.step
printed_part |  | Right Lower Cart Bottom | 1 |  |  | ABS |  |  | exports/stl/Right-lower-Cart-Bottom.stl | exports/step/Right-Lower-Cart-Bottom.step
printed_part |  | Right Upper Cart Plate | 1 |  |  | ABS |  |  | exports/stl/Right-Upper-Cart-Plate.stl | exports/step/Right-Upper-Cart-Plate.step
printed_part |  | Right Upper Cart Upper Mold | 1 |  |  | ABS |  |  | exports/stl/Right-Upper-Cart-Upper-Mold.stl | exports/step/Right-Upper-Cart-Upper-Mold.step
printed_part |  | Servo Wire Aligner | 1 |  |  | PLA |  |  | exports/stl/Servo-Wire-Aligner.stl | exports/step/Servo-Wire-Aligner.step
printed_part |  | Stepper to Drive Pulley Spacer | 2 |  |  | PLA |  |  | exports/stl/Stepper-to-Drive-Pulley-Spacer.stl | exports/step/Stepper-to-Drive-Pulley-Spacer.step
printed_part |  | Surface Roller | 10 |  |  | ABS |  |  | exports/stl/Surface-Roller.stl | exports/step/Surface-Roller.step
printed_part |  | Toolhead Cart Back | 1 |  |  | ABS |  |  | exports/stl/Toolhead-Cart-Back.stl | exports/step/Toolhead-Cart-Back.step
printed_part |  | Toolhead Cart Connector | 1 |  |  | PETG |  |  | exports/stl/Toolhead-Cart-connector.stl | exports/step/Toolhead-Cart-Connector.step
printed_part |  | Toolhead Front Cart | 1 |  |  | ABS |  |  | exports/stl/Toolhead-Front-Cart.stl | exports/step/Toolhead-Front-Cart.step

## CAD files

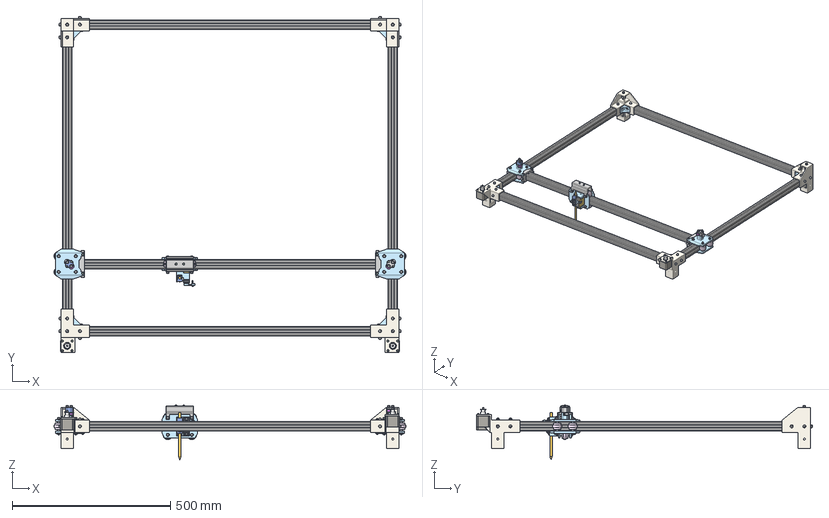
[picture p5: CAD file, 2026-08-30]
hardware/exports/assembly/pen-plotter-full-assembly.step
1113.5 x 1063.3 x 173.7 mm
Cart-to-Bearing Spacer x 24
m3 x 10 x 10
625 Bearing x 24
Right Upper Cart Upper Mold
m5 x 50 x 10
Extrusion Brackets x 4
m3 x 16 x 9
m5 nut x 18
m5 x 45 x 8
1 mm Spacer for Y Cart x 6
m3 washer x 18
Left Lower Cart Plate x 2
m6 x 12 x 22
Bearing-to-Bearing Internal Roller Spacer x 12
Right lower Cart Bottom
m5 washer x 18
Stepper Motor x 2
Toothed Idler Pulley x 6
m6 washer x 4
Pencil Housing Cap
1.5 mm M+U Spacer for Corner Brackets x 4
Surface Roller x 10
m3 x 25 x 4
m6 x 30 x 4
Gantry Extrusion
m3 nut x 2
Pencil Block
Length Extrusion x 2
Drive Pulley x 2
Width Extrusion x 2
Pencil Housing
Pen
20kg Servo
Back Corner Brackets x 2
GT2 Aluminum Timing Belt Clamp x 2
Toothless Idler Pulley x 2
Stepper to Drive Pulley Spacer x 2
7.25 mm L Spacer for Corner Brackets x 2
Belt Clamp Mount
Toolhead Front Cart
Right Corner Bracket
Left Upper Cart Upper Mold
0.5 mm Spacer for Y Cart x 2
Right Lower Cart Plate
m4 washer x 2
Cart Cart Plate x 2
Toolhead Cart connector
m3 x 6
m4 nut x 2
Left Corner Bracket
Securer
Modified Surface Roller x 2
m4 x 12 x 2
Toolhead Cart Back
Servo Horn

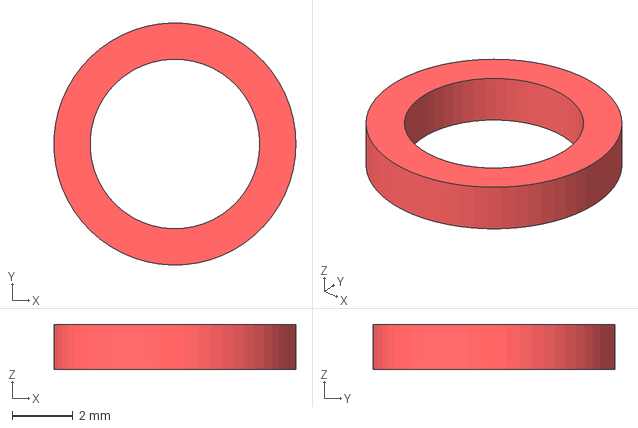
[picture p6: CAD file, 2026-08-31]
hardware/exports/step/1.5-mm-M+U-Spacer-for-Corner-Brackets.step
7.99 x 8.00 x 1.50 mm

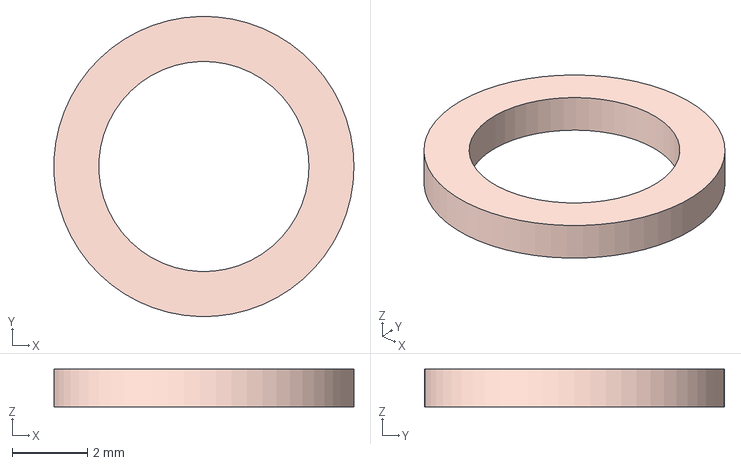
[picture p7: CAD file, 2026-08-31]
hardware/exports/step/1-mm-Spacer-for-Y-Cart.step
7.99 x 8.00 x 1.00 mm

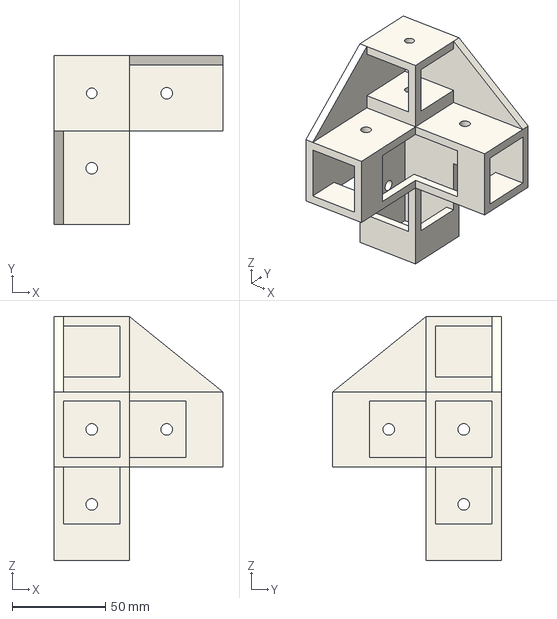
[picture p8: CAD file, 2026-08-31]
hardware/exports/step/Back-Corner-Brackets.step
90.2 x 90.2 x 130.5 mm

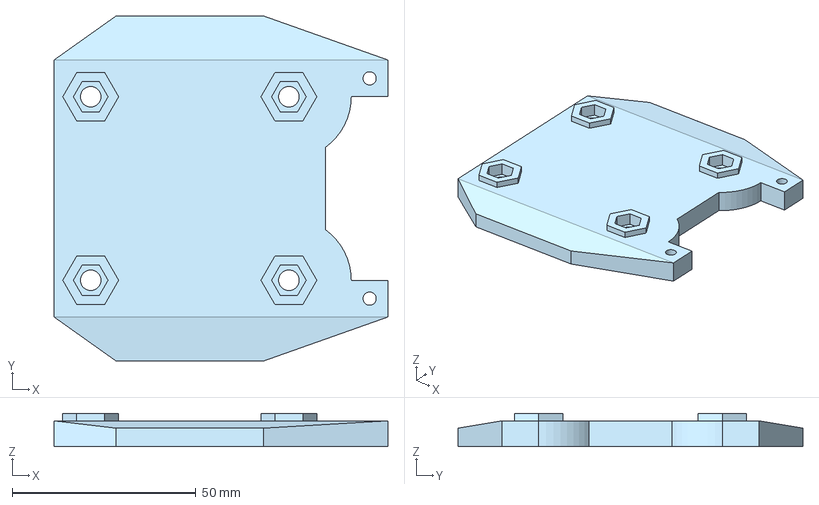
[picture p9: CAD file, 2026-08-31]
hardware/exports/step/Left-Lower-Cart-Plate.step
91.0 x 94.0 x 9.00 mm

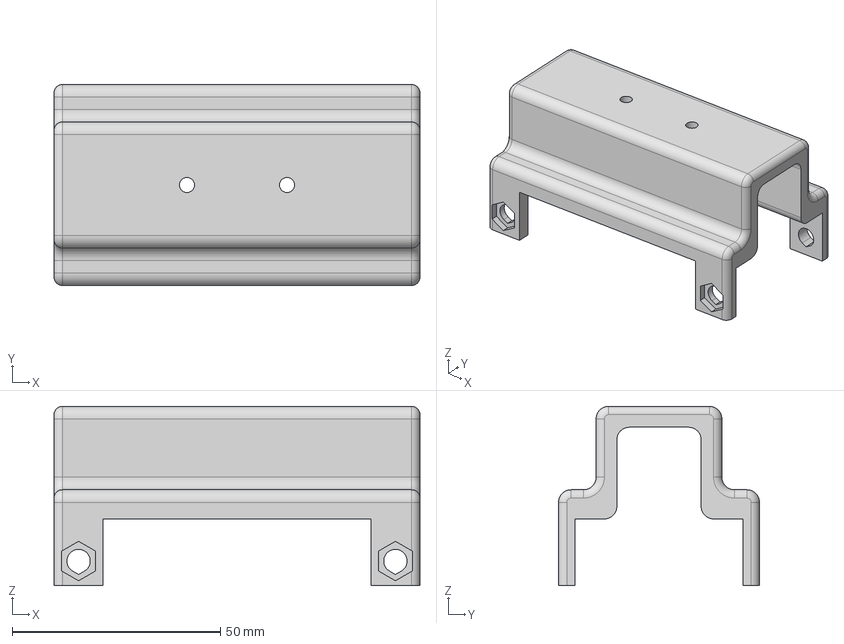
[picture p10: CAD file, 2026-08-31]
hardware/exports/step/Toolhead-Cart-Connector.step
87.8 x 48.2 x 43.0 mm

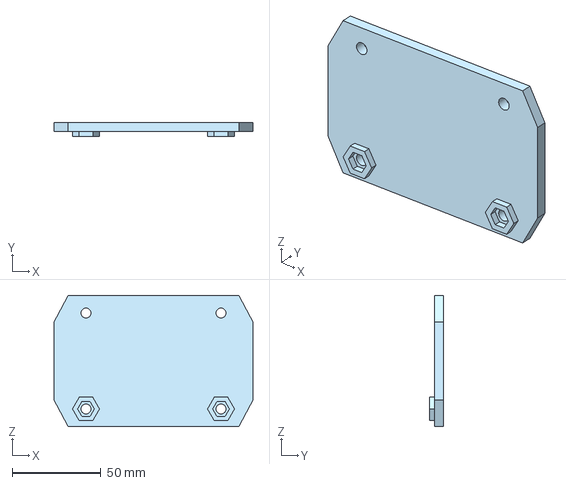
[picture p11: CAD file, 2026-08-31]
hardware/exports/step/Toolhead-Cart-Back.step
112.0 x 8.00 x 74.0 mm

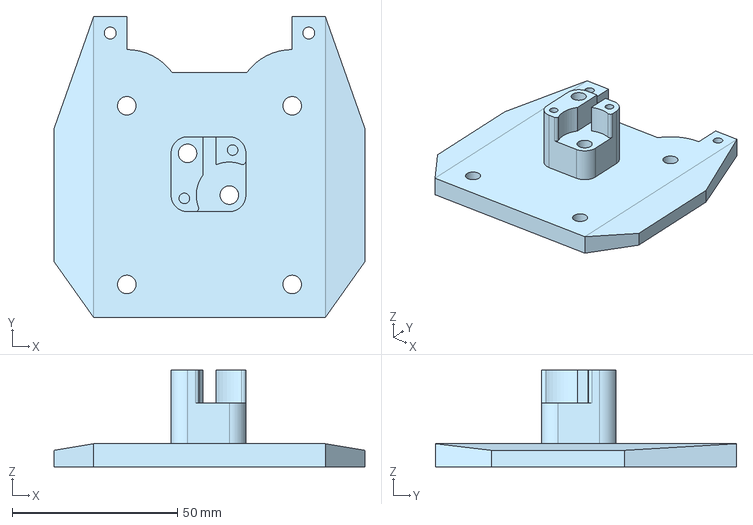
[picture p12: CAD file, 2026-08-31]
hardware/exports/step/Right-Upper-Cart-Plate.step
94.0 x 91.0 x 29.2 mm

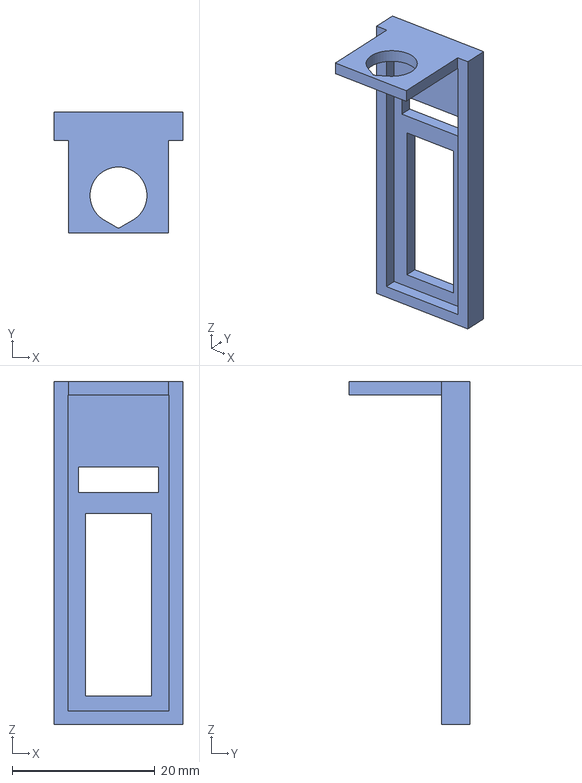
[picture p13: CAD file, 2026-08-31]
hardware/exports/step/Pencil-Housing-Cap.step
18.0 x 17.0 x 48.0 mm

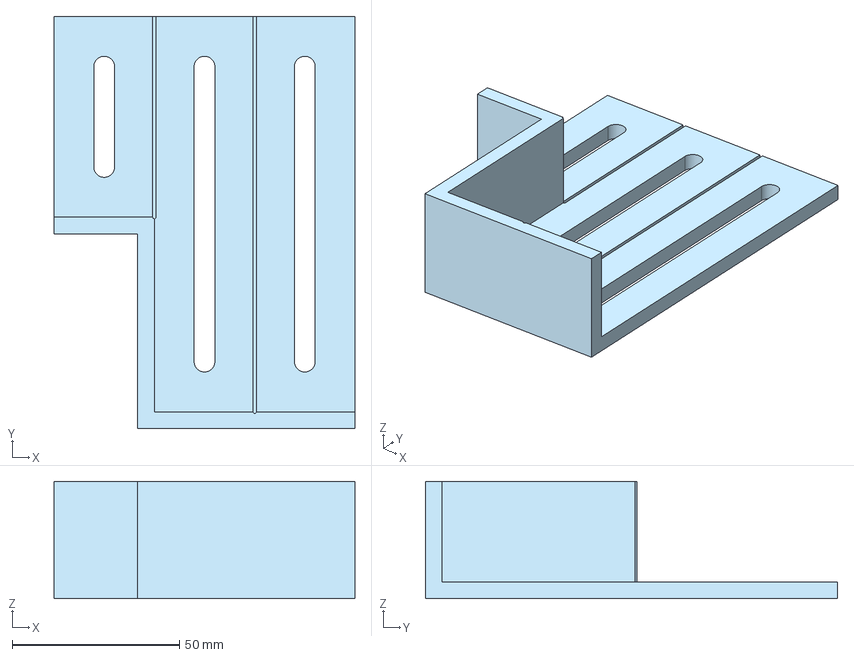
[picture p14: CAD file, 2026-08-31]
hardware/exports/step/Gantry-Extrusion-Jig.step
90.0 x 123.2 x 35.0 mm

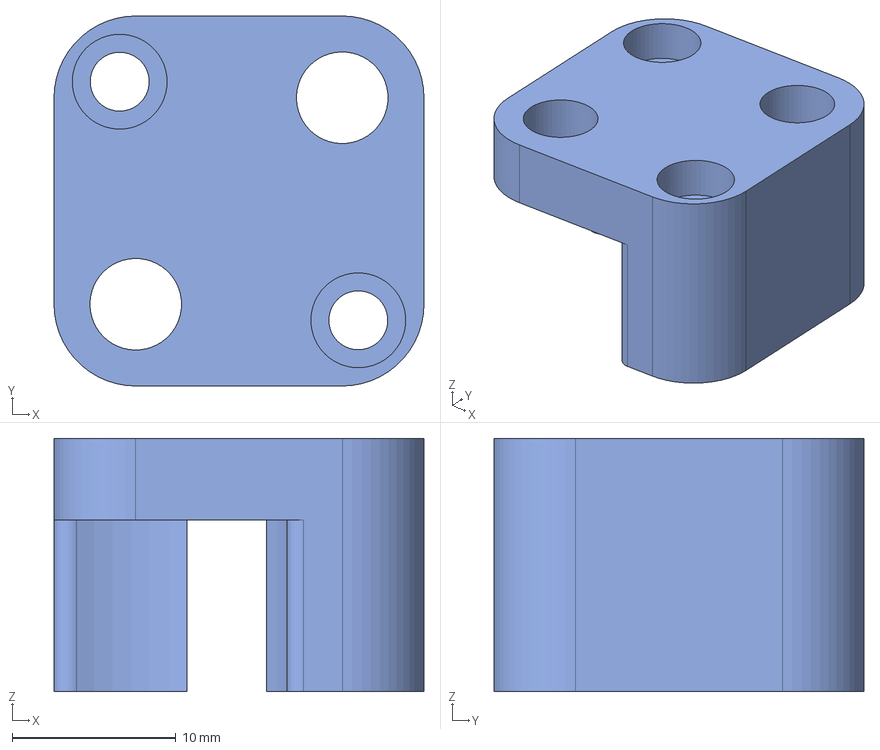
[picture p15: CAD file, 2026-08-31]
hardware/exports/step/Left-Upper-Cart-Upper-Mold.step
22.6 x 22.6 x 15.5 mm

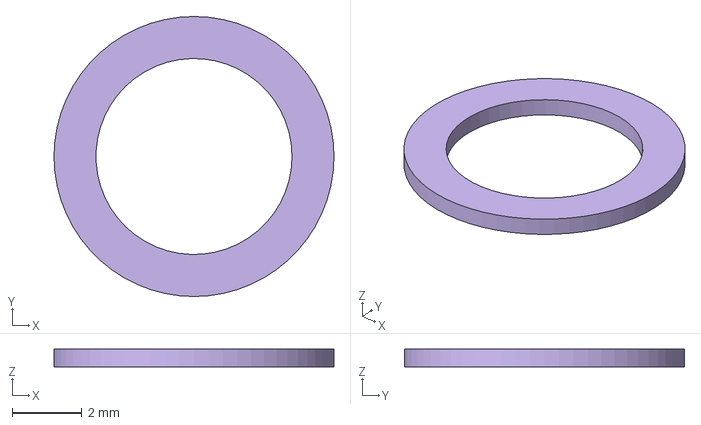
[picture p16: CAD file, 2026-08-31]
hardware/exports/step/0.5-mm-Spacer-for-Y-Cart.step
8.00 x 8.00 x 0.5 mm

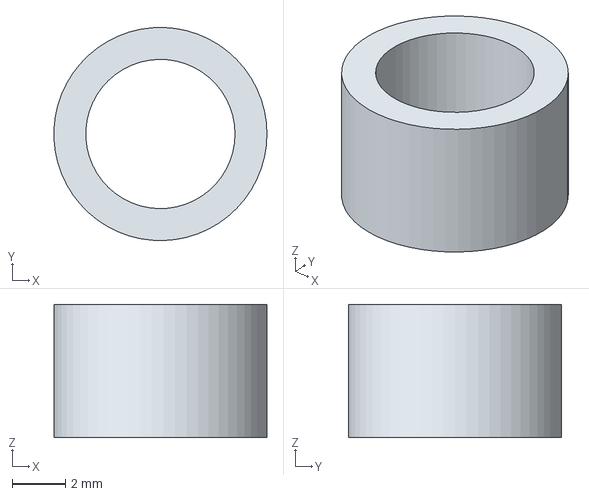
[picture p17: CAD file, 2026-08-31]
hardware/exports/step/Cart-to-Bearing-Spacer.step
7.99 x 8.00 x 5.00 mm

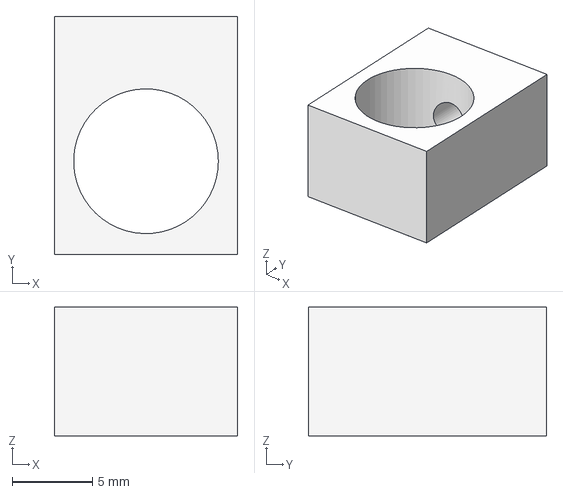
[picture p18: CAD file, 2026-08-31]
hardware/exports/step/Pencil-Block.step
11.4 x 14.8 x 8.00 mm

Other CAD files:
hardware/exports/step/Modified-Surface-Roller.step
hardware/exports/step/Belt-Clamp-Mount.step
hardware/exports/step/Bearing-to-Bearing-Internal-Roller-Spacer.step
hardware/exports/step/Pencil-Housing.step
hardware/exports/step/7.25-mm-L-Spacer-for-Corner-Brackets.step
hardware/exports/step/Cart-Cart-Plate.step
hardware/exports/step/Left-Corner-Bracket.step
hardware/exports/step/Left-Upper-Cart-Plate.step
hardware/exports/step/Pen-Adapter.step
hardware/exports/step/Right-Corner-Bracket.step
hardware/exports/step/Right-Lower-Cart-Bottom.step
hardware/exports/step/Right-Upper-Cart-Upper-Mold.step
hardware/exports/step/Servo-Wire-Aligner.step
hardware/exports/step/Stepper-to-Drive-Pulley-Spacer.step
hardware/exports/step/Surface-Roller.step
hardware/exports/step/Toolhead-Front-Cart.step
hardware/exports/stl/0.5-mm-Spacer-for-Y-Cart.stl
hardware/exports/stl/1-mm-Spacer-for-Y-Cart.stl
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

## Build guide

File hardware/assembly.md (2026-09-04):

# Assembly Guide

This guide explains the current build details for the CoreXY pen
plotter. The CAD and BOM remain the source of truth for mechanical part shapes
and counts; this file records the build order, electronics, wiring, and first
motion checks.

If you are building this and get stuck, feel free to reach out:
bcliu09@gmail.com.

## Mechanical Build

CAD reference render:

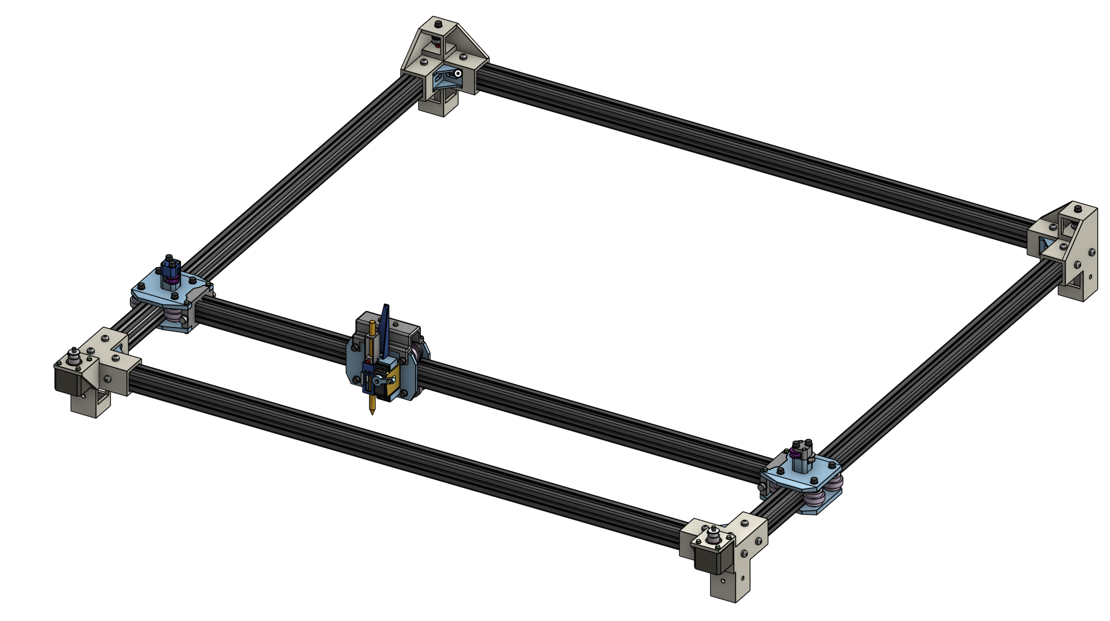
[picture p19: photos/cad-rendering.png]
CAD rendering of the plotter


Reference the Onshape assembly while building. The exported files are useful for
printing, but the Onshape assembly is still the easiest way to check how parts
are supposed to sit relative to each other.

1. Start the motor-side half of the frame. Push the uncut 1 meter length
   extrusions fully into the motor mount brackets, one on each side. Slide in the
   T-nuts needed to secure each extrusion to its corner bracket. Add an aluminum
   corner bracket into each corner now, while the corner is still easy to reach,
   and make sure each bracket sits snugly in the corner.
2. Take another extrusion for the width piece between the two motor corner
   mounts. Load the correct number of T-nuts into it before closing the frame.
   When this width extrusion is installed, it should not occupy the corner cube;
   the length extrusions should occupy that space. Tighten the M6 x 12 bolts into
   the T-nuts and through the aluminum corner brackets.
3. At this point, the frame should look like a U shape. Next, cut the gantry
   extrusion. Cut 58.2 mm off a full 1 meter extrusion. Cutting a little too much
   is better than cutting too little, because an oversized gantry extrusion will
   fight the carts and make assembly harder. Once the gantry is cut, take the two
   cart-cart plates and press or lightly hammer them onto each side.
4. Pre-assemble the Y carts before sliding the gantry into the full frame. Before
   doing the rollers, assemble the upper mold/idler section. Insert the M5 screws
   into the upper mold, add the thin 0.5 mm and 1 mm printed spacers where they
   belong, add the idler pulleys, pass the screws through the cart top plate, and
   secure them with M5 nuts. The extra M3 holes on the Y carts can be mounted if
   you want more rigidity.
5. Build the rollers between the cart top and bottom plates. Starting from the
   top plate, load each M5 screw with a washer, add the cart-to-bearing spacer,
   add a 625 bearing, add the printed surface roller, add the bearing-to-bearing
   internal spacer, add the second 625 bearing, then add the outside
   cart-to-bearing spacer. Repeat this stack for all rollers, then close the cart
   with M5 nuts.
6. Repeat the Y-cart assembly for both sides. Then mesh the cart-cart plates on
   the gantry extrusion with the two Y carts and slide the whole gantry/Y-cart
   assembly onto the frame.
7. Assemble the two identical far-side/back corner brackets. For each pulley
   stack, insert the M5 screw with washer, then stack the upper spacer, toothed
   idler, middle spacer, toothed idler, and bottom spacer. Put the M5 nut into
   the extrusion groove and tighten the stack enough to hold it, but loose enough
   that the pulleys can still spin freely. Do this for both far-side brackets.
8. Take a full 1 meter width extrusion, load its T-nuts, and mount the two
   far-side corner brackets onto each end. Again, do not slide this width
   extrusion into the corner cube; that space is for the length extrusions that
   will slide in next. Before closing the frame, add the aluminum corner brackets
   onto this width extrusion using the M6 x 12 bolts and the loaded T-nuts. After
   this, there should be a clean square opening down through each corner bracket
   where the length extrusion can enter.
9. Load the correct number of T-nuts onto the left and right length extrusions.
   Carefully slide both length extrusions into the far-side corner bracket holes
   at the same time, inching each side forward evenly so the frame does not twist.
   Make sure the gantry assembly is already on the length extrusions before the
   far side is closed. A light hammer tap may be needed to get the fit snug.
10. Install the M3 rigidity screws and washers that connect the cart-cart plates
    to the Y carts. Tighten all remaining M6 x 12 frame bolts. The frame should
    now feel rigid. Mount the two NEMA 17 motors using M3 x 10 screws and washers.
11. Pre-assemble the toolhead. First mount the servo with four M3 screws. Then
    take the two toolhead plates and use the same roller-stack process to mount
    the two bottom rollers. From the side, the partial toolhead assembly should
    look like a U shape that can slide onto the gantry.
12. Route the belts before fully closing the toolhead. Take one 5 meter belt, run
    it through its CoreXY layer, and bring both belt ends to the middle of the
    gantry. Cut it so there is about 1 cm of gap between the two ends. Repeat for
    the second belt layer. Use the belt clamp mount, aluminum belt clamps, and M4
    screws to pin the belts down. Tension both belts evenly. Do this while the
    gantry is pushed against an edge so the frame is held rectangular while the
    belts are tightened. Once the belts are clamped, use M3 screws to mount the
    belt clamp mount onto the large U-shaped toolhead mount.
13. Slide the partially assembled toolhead onto the gantry from the bottom and
    align it with the belt mount. Pre-assemble each modified roller with a
    bearing-to-bearing spacer sandwiched between two 625 bearings. Then use
    tweezers to push the M5 screw through the top belt mount, the cart plate, a
    cart-to-bearing spacer, the modified roller, another cart-to-bearing spacer,
    the other cart plate, the lower belt mount, and finally into an M5 nut. Repeat
    this for both upper rollers.
14. Assemble the pencil mount. Put the pencil block into the pencil housing, add
    the spring, install the cap, and slide the housing into place. Push an M3
    screw through the outer hole of the servo horn and into the horizontal groove
    of the pencil housing cap. Use two nuts to lock this M3 screw so it holds the
    cap position. Super glue the small slider securer near the bottom of the left
    side of the slider rail, but do not glue it to the moving pencil housing.
    Finally, glue the servo wire aligner so the servo wire exits vertically, then
    use the zip tie to lock the wire down.

Toolhead detail:

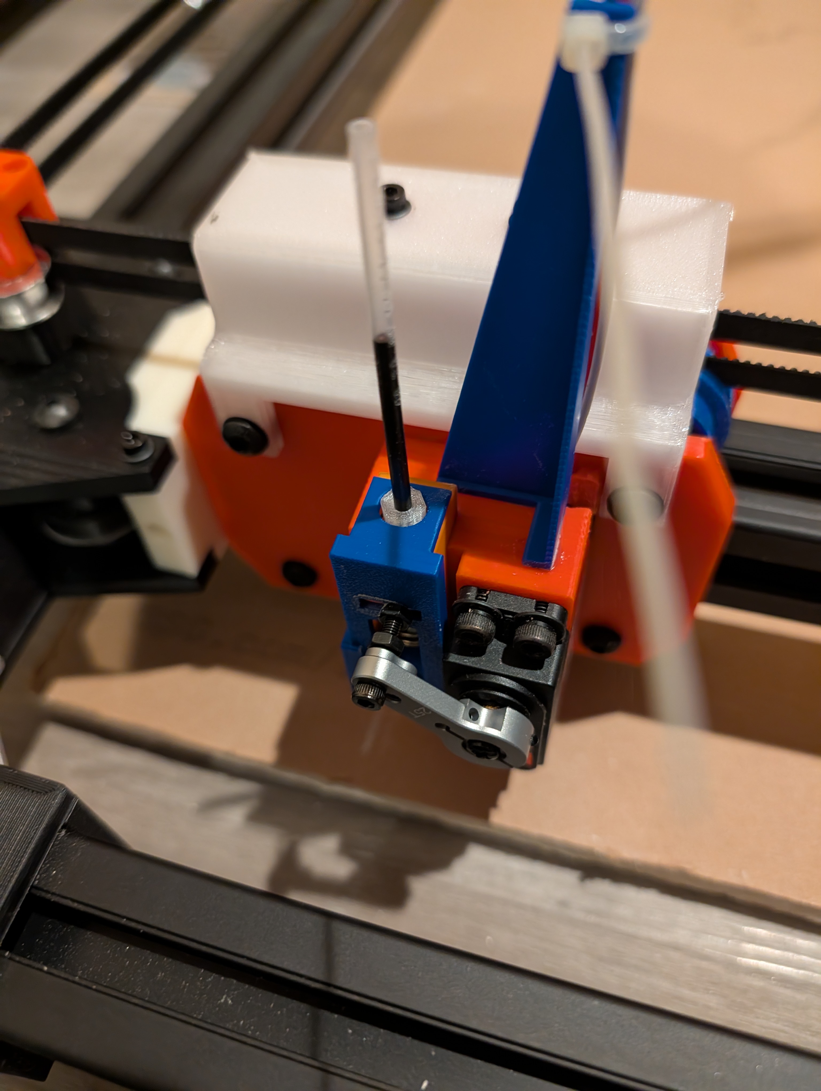
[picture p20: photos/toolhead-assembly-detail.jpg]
Toolhead assembly detail


15. Wire the motors by plugging the NEMA 17 four-pin connectors into the X and Y
    driver sockets on the CNC shield. For the servo, chain jumper wires together
    so the servo lead can reach the electronics. In this build, the best solution
    was to make a simple overhead support, like a tripod or suspended arm, that
    holds the servo wire above the center of the machine. The wire should be able
    to reach all four corners without sagging into the belts or onto the paper.
16. Set the DRV8825 current limit to about 0.45-0.5A before serious motion
    testing. If you have not adjusted DRV8825 current before, look up the current
    limit procedure for your exact driver board and measure carefully. After the
    drivers are set, install their heatsinks, place the drivers into the CNC
    shield in the correct orientation, and plug the shield onto the Arduino Uno.
    Wire the servo and external 5V supply using the servo anti-twitch circuit
    described below.

## Electronics

Current electronics:

```text
Arduino Uno
CNC Shield V3
DRV8825 stepper drivers
two NEMA 17 stepper motors
servo for pen lift
external motor power supply for CNC shield
external 5V supply for servo
IRLZ44N N-channel MOSFET for servo power switching
```

Reference overview of the current electronics setup:

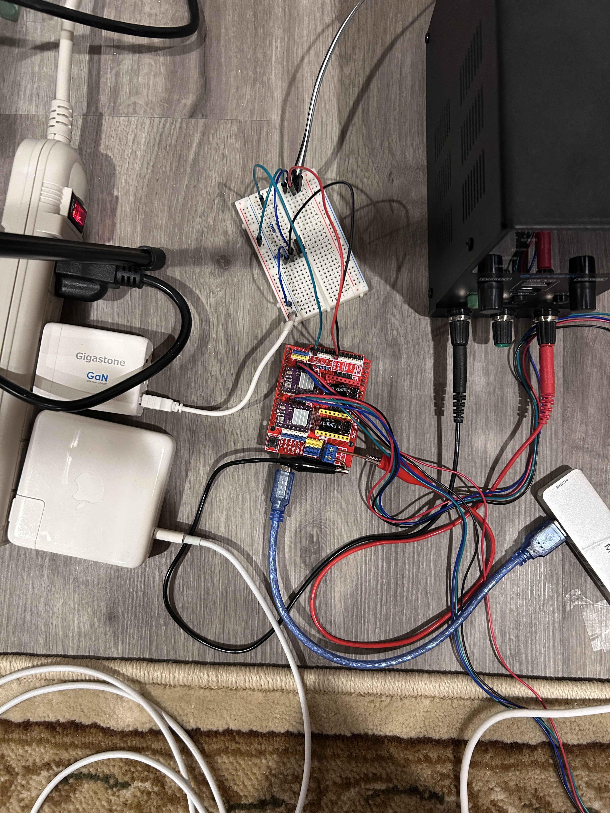
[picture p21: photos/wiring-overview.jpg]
Wiring overview


## CNC Shield Wiring

Stepper mapping:

```text
CNC Shield X driver socket = CoreXY motor A
CNC Shield Y driver socket = CoreXY motor B
```

Arduino/CNC shield pin mapping:

```text
D2  = X step = CoreXY motor A step
D3  = Y step = CoreXY motor B step
D5  = X dir  = CoreXY motor A dir
D6  = Y dir  = CoreXY motor B dir
D8  = stepper enable, active LOW
D11 = Z-limit signal, servo power MOSFET gate
D12 = SpnEn, servo signal
```

The firmware assumes DRV8825 drivers are configured for `1/32` microstepping:

```text
GT2 belt
20 tooth pulley
1.8 degree stepper motor
1/32 microstepping
160 steps/mm
```

## Servo Anti-Twitch Power Wiring

The servo is powered through an IRLZ44N N-channel MOSFET so it stays off during
Arduino boot/reset. This avoids the startup twitch that happened when the servo
received unstable power or signal during boot.

Breadboard reference for the servo/transistor wiring:

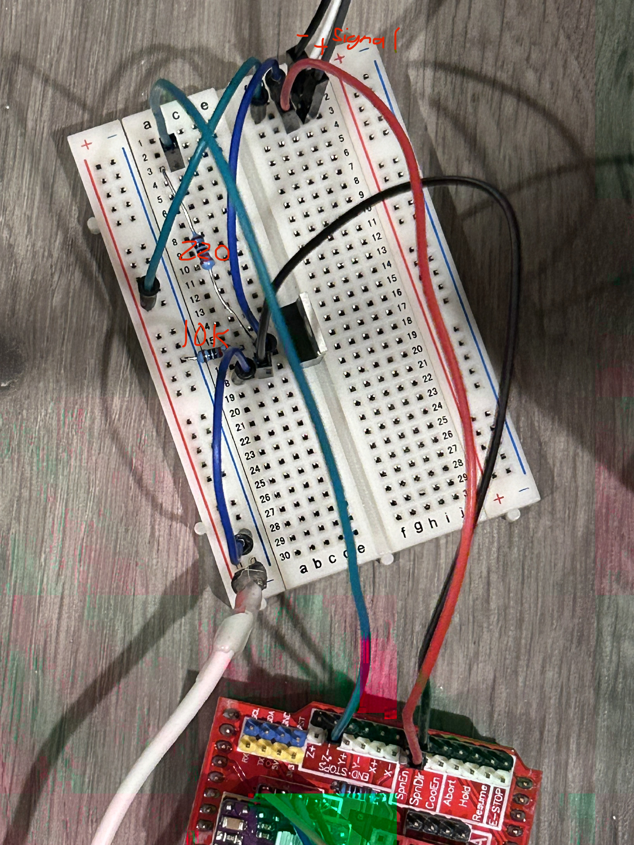
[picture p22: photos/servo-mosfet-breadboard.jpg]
Servo MOSFET breadboard wiring


With the IRLZ44N front/text side facing you and legs pointing downward:

```text
left pin   = gate
middle pin = drain
right pin  = source
```

Wire the servo power circuit like this:

```text
Servo red wire       -> external 5V +
Servo brown/black    -> IRLZ44N drain
IRLZ44N source       -> external 5V GND
IRLZ44N source       -> Arduino/CNC shield GND
Servo orange/yellow  -> CNC shield SpnEn / Arduino D12
CNC shield D11       -> 220 ohm resistor -> IRLZ44N gate
IRLZ44N gate         -> 10k ohm pulldown resistor -> GND
```

All grounds must be common:

```text
Arduino/CNC shield GND
external servo 5V supply GND
IRLZ44N source
motor supply ground, if the supply setup exposes a common ground point
```

Optional signal pulldown:

```text
D12 / SpnEn servo signal -> 10k ohm resistor -> GND
```

Optional signal protection:

```text
D12 / SpnEn -> 1k ohm resistor -> servo signal wire
```

The required anti-twitch part is the gate pulldown:

```text
IRLZ44N gate -> 10k ohm resistor -> GND
```

The firmware starts with servo power off:

```cpp
pinMode(SERVO_POWER_PIN, OUTPUT);
digitalWrite(SERVO_POWER_PIN, LOW);
```

When a pen command is sent, the firmware writes the target up position, attaches
the servo signal, waits briefly, turns on MOSFET power through `D11`, then moves
the servo. When servo power is turned off, the firmware moves the pen up, turns
off MOSFET power, then detaches the servo signal.

## Machine Coordinates

The plotter uses machine coordinates:

```text
X0 Y0     = bottom-left manual home
X203 Y185 = center
X406 Y370 = far corner
```

Do not treat `0,0` as the center. The known-good firmware assumes bottom-left is
home.

Current soft limits:

```text
X_MAX = 406.0 mm
Y_MAX = 370.0 mm
```

## First Power-On Checks

Before uploading or moving:

1. Confirm the DRV8825 drivers are oriented correctly on the CNC shield.
2. Confirm the motor power supply voltage and polarity.
3. Confirm the servo external 5V polarity.
4. Confirm the Arduino/CNC shield ground and servo supply ground are common.
5. Confirm the MOSFET gate has the 10k pulldown to ground.
6. Confirm the servo red wire is not powered from the Arduino 5V pin.
7. Confirm the gantry can travel across the full drawing area without binding, rubbing, or pulling wires tight.

Then upload the firmware:

```bash
cd firmware
pio run -e uno -t upload
```

Open the serial monitor:

```bash
cd firmware
pio device monitor -e uno
```

Manual homing sequence:

```text
moff
```

Move the gantry/toolhead by hand to the bottom-left corner.

```text
mon
h
p
```

Basic servo test:

```text
u
d
u
soff
```

Basic motion test:

```text
g 203 185
g 0 0
```

If center is correct, test the far corner carefully:

```text
g 406 370
```

## Serial Commands

```text
?              show help
h              set current position as X0 Y0
p              print current position and settings
r dx dy         relative move in mm, example: r 10 0
g x y           absolute move in mm, example: g 203 185
c x y radius    draw circle, example: c 203 185 40
l xmax ymax     set soft limits, example: l 406 370
s fastDelay     set top-speed step delay, example: s 50
accel n         set acceleration in steps/sec^2, example: accel 10000
mon             enable stepper drivers
moff            disable stepper drivers
son             servo power on
soff            servo power off
u               pen up
d               pen down
a angle         servo angle, example: a 100
test            servo power on, up, down, up, off
```

Lower `s` values are faster because the command controls the top-speed step
delay in microseconds. The current prototype firmware blocks values below `1`.

Motion uses an acceleration-limited curve. Short moves automatically stay slower
if there is not enough distance to accelerate and decelerate gently.

## Sending A G-code File

Launch Plotter Studio:

```bash
cd firmware
python3 -m venv .venv
.venv/bin/python -m pip install -r tools/requirements.txt
.venv/bin/python tools/plotter_studio.py
```

Then open `http://127.0.0.1:8765`.

Send the square smoke test:

```bash
cd firmware
pio run -e uno -t upload && .venv/bin/python tools/send_gcode.py --confirm-home examples/square.gcode
```

The sender prompts you to manually place the toolhead at bottom-left home before
it sends the `G28 P1` home-confirmation command.

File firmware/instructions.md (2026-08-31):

# Plotter Studio Instructions

Plotter Studio is the app used to prepare artwork and send it to the CoreXY pen
plotter. It is meant to replace the terminal workflow for normal use.

## Launch The App

From the repo root:

```bash
firmware/tools/build_macos_app.sh
open "Plotter Studio.app"
```

The app starts a local backend at `http://127.0.0.1:8765` inside the native Mac
window. If the app cannot start, check `firmware/.plotter-app/desktop.log`.

The browser version can also be launched from this folder:

```bash
tools/run_plotter_studio.sh
```

Then open:

```text
http://127.0.0.1:8765
```

## Upload Firmware

Install the PlatformIO extension in VS Code, plug in the Arduino Uno, then run
from this `firmware/` folder:

```bash
pio run -e uno
pio run -e uno -t upload
```

In VS Code's PlatformIO sidebar, the checkmark builds and the right arrow
uploads. Close Plotter Studio, serial monitor, or any other app using the Arduino
port before uploading, because only one program can own the serial port at once.

Firmware only needs to be uploaded when `src/main.cpp` changes. Uploading SVGs
or images does not require reflashing the Arduino.

## Normal Plotting Workflow

1. Open Plotter Studio.
2. Go to Device and connect to the Arduino.
3. Turn motors off.
4. Move the toolhead by hand to the bottom-left home position.
5. Turn motors on.
6. Press `Confirm X0 Y0`.
7. Go to Prepare and open/import artwork.
8. Move, scale, and rotate the artwork on the plate.
9. Press `Slice Plate`.
10. Review the toolpath and gcode in Preview.
11. Press `Confirm Slice`.
12. Return to Device and press `Send To Plotter`.

Before a real drawing job starts, the app lifts the pen so an accidental pen-down
state from manual testing does not drag across the page.

## Prepare

Prepare is where artwork is placed before the machine moves.

Use `Open Image` for SVG, PNG, JPG, GIF, BMP, or WebP files. SVG files are loaded
as vector paths. Raster files open in a tracing popup first, where the image is
converted into drawable vector strokes.

The import popup has controls for edge threshold, simplify amount, trace size,
minimum stroke length, and link gap. If a trace is taking too long, changing a
slider cancels the old trace and starts a new one. The popup also shows progress
while tracing.

Use `Load Square` or `Load Circle` for quick test drawings.

Artwork on the plate can be selected, moved, resized, rotated, deleted, undone,
and redone. Dragging side handles changes one side. Dragging corners scales from
the adjacent edges. Holding shift keeps proportions. Rotation snaps to common
angles, and edges can snap to paper margins.

## Paper Mode

The paper dropdown controls what part of the machine area is considered usable.

`Full Canvas` uses the whole `406 x 370` machine coordinate area. `Letter`
displays a centered landscape Letter paper area inside the same full machine
canvas. The Letter rectangle is currently `140 x 108.182` machine units centered
at `X203 Y185`.

The gray overlay shows the margin/safety area. The grid still remains visible
under it so scale and placement are easier to judge.

To set up Letter paper physically, first put a larger backing sheet or board
under the plotter and keep it fixed in place. In Plotter Studio, set Paper to
`Letter`, set Margin to `0`, then use `Load Square`. Resize and drag the square
so its edges snap to the four edges of the Letter paper rectangle. Slice and draw
that rectangle onto the larger backing surface. This creates a permanent-ish
placement outline showing where Letter paper should sit.

After that outline exists, place Letter paper on top of the drawn rectangle and
tape it down so it cannot slide. Then load the real drawing normally, keep Paper
set to `Letter`, and raise Margin back to the safer value you actually want for
the job. The app will block anything outside the Letter paper rectangle and warn
if the drawing enters the margin.

If the art goes outside the selected paper, slicing is blocked. If it enters the
margin but stays on the paper, the app warns you but still allows slicing.

## Preview

Preview is the locked toolpath view. It shows what will be drawn after slicing,
plus the generated gcode. This is where you check that the plate looks right
before committing the job to the Device tab.

`Confirm Slice` does not start the machine. It only accepts the sliced toolpath
and moves you to Device, where the actual send button lives.

## Device

Device is for connecting to the Arduino, homing, manual control, live tuning, and
starting jobs.

Common controls:

```text
Motors On/Off        enable or release the stepper drivers
Confirm X0 Y0        tell firmware the current position is home
Jog arrows           move X/Y by the selected jog distance
Pen Up / Pen Down    move the servo and update the pen state buttons
Servo Off            lift pen and cut servo power
Speed delay          lower number means faster stepping
Acceleration         higher number reaches speed faster
Pen up/down wait     servo settle times
Pen up lift          percent of the full up angle to use
Stop                 abort, pen up, return home, reset progress
```

Jogging is manual control, so it does not automatically lift the pen. If the pen
is down and you jog, it will draw.

During a running job, jog controls are disabled. Use pause/stop before manual
movement.

## Job Minimap

After a slice is confirmed, the Device tab shows a job minimap. The remaining
path is gray, completed drawn path is teal, and the moving toolhead dot estimates
where the machine is between firmware acknowledgements. It resyncs whenever the
firmware reports that a gcode line finished.

When the job finishes, the minimap stays filled until `Stop` is pressed. Stop
acts like reset: it lifts the pen, returns home if possible, clears progress, and
hides the job map.

## Serial Port Notes

Plotter Studio connects over USB serial at `115200` baud. If connection fails
with a busy-resource error, close other serial monitors, Arduino IDE windows,
PlatformIO monitor sessions, or old Plotter Studio instances.

For raw debugging only:

```bash
pio device monitor -e uno
```

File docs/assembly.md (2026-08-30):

# Assembly Guide

This guide captures the current known-good build details for the CoreXY pen
plotter. The CAD and BOM remain the source of truth for mechanical part shapes
and counts; this file records the build order, electronics, wiring, and first
motion checks.

## Mechanical Build

1. Build the rectangular frame from the length and width extrusions.
2. Install the corner brackets and pulley stacks from the CAD assembly.
3. Mount the two NEMA 17 stepper motors on the motor-side corners.
4. Install the gantry extrusion and left/right cart plates.
5. Install the moving toolhead cart, belt clamp mount, pencil housing, and servo
   lift mechanism.
6. Route and tension the CoreXY belts so the gantry moves smoothly by hand with
   the motors disabled.

Before powering motors, confirm the gantry can travel across the full drawing
area without binding, rubbing, or pulling wires tight.

## Electronics

Current electronics:

```text
Arduino Uno
CNC Shield V3
DRV8825 stepper drivers
two NEMA 17 stepper motors
servo for pen lift
external motor power supply for CNC shield
external 5V supply for servo
IRLZ44N N-channel MOSFET for servo power switching
```

## CNC Shield Wiring

Stepper mapping:

```text
CNC Shield X driver socket = CoreXY motor A
CNC Shield Y driver socket = CoreXY motor B
```

Arduino/CNC shield pin mapping:

```text
D2  = X step = CoreXY motor A step
D3  = Y step = CoreXY motor B step
D5  = X dir  = CoreXY motor A dir
D6  = Y dir  = CoreXY motor B dir
D8  = stepper enable, active LOW
D11 = Z-limit signal, servo power MOSFET gate
D12 = SpnEn, servo signal
```

The firmware assumes DRV8825 drivers are configured for `1/32` microstepping:

```text
GT2 belt
20 tooth pulley
1.8 degree stepper motor
1/32 microstepping
160 steps/mm
```

## Servo Anti-Twitch Power Wiring

The servo is powered through an IRLZ44N N-channel MOSFET so it stays off during
Arduino boot/reset. This avoids the startup twitch that happened when the servo
received unstable power or signal during boot.

With the IRLZ44N front/text side facing you and legs pointing downward:

```text
left pin   = gate
middle pin = drain
right pin  = source
```

Wire the servo power circuit like this:

```text
Servo red wire       -> external 5V +
Servo brown/black    -> IRLZ44N drain
IRLZ44N source       -> external 5V GND
IRLZ44N source       -> Arduino/CNC shield GND
Servo orange/yellow  -> CNC shield SpnEn / Arduino D12
CNC shield D11       -> 220 ohm resistor -> IRLZ44N gate
IRLZ44N gate         -> 10k ohm pulldown resistor -> GND
```

All grounds must be common:

```text
Arduino/CNC shield GND
external servo 5V supply GND
IRLZ44N source
motor supply ground, if the supply setup exposes a common ground point
```

Optional signal pulldown:

```text
D12 / SpnEn servo signal -> 10k ohm resistor -> GND
```

Optional signal protection:

```text
D12 / SpnEn -> 1k ohm resistor -> servo signal wire
```

The required anti-twitch part is the gate pulldown:

```text
IRLZ44N gate -> 10k ohm resistor -> GND
```

The firmware starts with servo power off:

```cpp
pinMode(SERVO_POWER_PIN, OUTPUT);
digitalWrite(SERVO_POWER_PIN, LOW);
```

When a pen command is sent, the firmware writes the target up position, attaches
the servo signal, waits briefly, turns on MOSFET power through `D11`, then moves
the servo. When servo power is turned off, the firmware moves the pen up, turns
off MOSFET power, then detaches the servo signal.

## Machine Coordinates

The plotter uses machine coordinates:

```text
X0 Y0     = bottom-left manual home
X203 Y185 = center
X406 Y370 = far corner
```

Do not treat `0,0` as the center. The known-good firmware assumes bottom-left is
home.

Current soft limits:

```text
X_MAX = 406.0 mm
Y_MAX = 370.0 mm
```

## First Power-On Checks

Before uploading or moving:

1. Confirm the DRV8825 drivers are oriented correctly on the CNC shield.
2. Confirm the motor power supply voltage and polarity.
3. Confirm the servo external 5V polarity.
4. Confirm the Arduino/CNC shield ground and servo supply ground are common.
5. Confirm the MOSFET gate has the 10k pulldown to ground.
6. Confirm the servo red wire is not powered from the Arduino 5V pin.

Then upload the firmware:

```bash
pio run -e uno -t upload
```

Open the serial monitor:

```bash
pio device monitor -e uno
```

Manual homing sequence:

```text
moff
```

Move the gantry/toolhead by hand to the bottom-left corner.

```text
mon
h
p
```

Basic servo test:

```text
u
d
u
soff
```

Basic motion test:

```text
g 203 185
g 0 0
```

If center is correct, test the far corner carefully:

```text
g 406 370
```

## Serial Commands

```text
?              show help
h              set current position as X0 Y0
p              print current position and settings
r dx dy         relative move in mm, example: r 10 0
g x y           absolute move in mm, example: g 203 185
c x y radius    draw circle, example: c 203 185 40
l xmax ymax     set soft limits, example: l 406 370
s fastDelay     set top-speed step delay, example: s 50
accel n         set acceleration in steps/sec^2, example: accel 10000
mon             enable stepper drivers
moff            disable stepper drivers
son             servo power on
soff            servo power off
u               pen up
d               pen down
a angle         servo angle, example: a 100
test            servo power on, up, down, up, off
```

Lower `s` values are faster because the command controls the top-speed step
delay in microseconds. The current prototype firmware blocks values below `1`.

Motion uses an acceleration-limited curve. Short moves automatically stay slower
if there is not enough distance to accelerate and decelerate gently.

## Sending A G-code File

Launch Plotter Studio:

```bash
python3 -m venv .venv
.venv/bin/python -m pip install -r tools/requirements.txt
.venv/bin/python tools/plotter_studio.py
```

Then open `http://127.0.0.1:8765`.

Send the square smoke test:

```bash
pio run -e uno -t upload && .venv/bin/python tools/send_gcode.py --confirm-home examples/square.gcode
```

The sender prompts you to manually place the toolhead at bottom-left home before
it sends the `G28 P1` home-confirmation command.

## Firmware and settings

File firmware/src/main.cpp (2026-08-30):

#include <Arduino.h>
#include <Servo.h>

const int A_STEP = 2;  // CNC Shield X driver = CoreXY motor A
const int B_STEP = 3;  // CNC Shield Y driver = CoreXY motor B
const int A_DIR = 5;
const int B_DIR = 6;
const int EN_PIN = 8;  // active LOW

const int SERVO_POWER_PIN = 11;  // CNC Shield Z-limit signal -> MOSFET gate
const int SERVO_PIN = 12;        // CNC Shield SpnEn -> servo signal

const int PEN_UP = 80;
const int PEN_DOWN = 130;
int penUpDelay = 200;
int penDownDelay = 600;
int penUpLiftPercent = 100;

const int MIN_STEP_DELAY = 1;
const int DEFAULT_FAST_DELAY = 50;
const int START_STEP_DELAY = 600;
const float BEZIER_SAMPLE_MM = 1.0;
const int BEZIER_MIN_SEGMENTS = 8;
const int BEZIER_MAX_SEGMENTS = 220;
const float DEFAULT_ACCEL_STEPS_PER_SECOND2 = 10000.0;

// GT2 belt, 20T pulley, 1.8 degree motor, 1/32 microstepping:
// 200 * 32 / (20 * 2) = 160 steps/mm
const float STEPS_PER_MM = 160.0;

float X_MAX = 406.0;
float Y_MAX = 370.0;

float currentX = 0.0;
float currentY = 0.0;

// Higher delay = slower motion. Lower delay = faster motion.
int fastDelay = DEFAULT_FAST_DELAY;
float accelStepsPerSecond2 = DEFAULT_ACCEL_STEPS_PER_SECOND2;

bool servoPowered = false;
bool motorsEnabled = false;
bool homeConfirmed = false;
volatile bool abortRequested = false;

String inputLine = "";
Servo penServo;

void processLine(String line);
void processManualCommand(String cmd);
bool processGCode(String line);
String stripGCodeComments(String line);
bool pollRealtimeAbort();
void clearMotionAbort();
bool getWord(const String &line, char letter, float &value);
void confirmManualHome();
void printHelp();
void printGCodeHelp();
void printPosition();
void setMotorsEnabled(bool enabled);
void servoPowerOn();
void servoPowerOff();
void penUp();
void penDown();
int effectivePenUpAngle();
bool setPenDelay(char which, int newDelay, bool report);
bool setPenUpLiftPercent(int newPercent, bool report);
bool drawCircle(float centerX, float centerY, float radius, bool report);
bool moveTo(float targetX, float targetY, bool report);
bool bezierTo(float control1X, float control1Y, float control2X, float control2Y,
              float targetX, float targetY, bool report);
float cubicPoint(float p0, float p1, float p2, float p3, float t);
int bezierSegmentCount(float startX, float startY, float control1X, float control1Y,
                       float control2X, float control2Y, float targetX, float targetY);
void coreXYStepsBetween(float fromX, float fromY, float toX, float toY,
                        long &aSteps, long &bSteps);
long maxCoreXYSteps(long aSteps, long bSteps);
long stepCoreXY(long aSteps, long bSteps);
long stepCoreXYProfile(long aSteps, long bSteps, long &profileStep, long profileSteps);
int motionDelayForStep(long stepIndex, long totalSteps);
bool setStepDelay(int newDelay, bool report);
void setFeedRate(float feedRateMmPerMin, bool report);
bool setAcceleration(float newAccel, bool report);

void setup() {
  pinMode(A_STEP, OUTPUT);
  pinMode(B_STEP, OUTPUT);
  pinMode(A_DIR, OUTPUT);
  pinMode(B_DIR, OUTPUT);
  pinMode(EN_PIN, OUTPUT);

  pinMode(SERVO_POWER_PIN, OUTPUT);
  digitalWrite(SERVO_POWER_PIN, LOW);
  setMotorsEnabled(true);

  Serial.begin(115200);
  delay(500);

  printHelp();
  Serial.println(F("Startup state: servo power OFF; home not confirmed."));
  printPosition();
}

void loop() {
  while (Serial.available()) {
    char c = Serial.read();

    if (c == '!' || c == 24) {
      abortRequested = true;
      continue;
    }

    if (c == '\n' || c == '\r') {
      inputLine.trim();

      if (inputLine.length() > 0) {
        processLine(inputLine);
        inputLine = "";
      }
    } else {
      inputLine += c;
    }
  }
}

void processLine(String line) {
  line.trim();

  if (line.length() == 0) {
    return;
  }

  String cleaned = stripGCodeComments(line);
  cleaned.trim();

  if (cleaned.length() == 0) {
    Serial.println(F("ok"));
    return;
  }

  cleaned.toLowerCase();

  if (cleaned == "!" || cleaned == "abort" || cleaned == "stop") {
    abortRequested = true;
    Serial.println(F("Realtime abort requested."));
    Serial.println(F("ok"));
    return;
  }

  clearMotionAbort();

  char first = cleaned.charAt(0);
  if ((first == 'g' || first == 'm') && cleaned.length() > 1 &&
      isDigit(cleaned.charAt(1))) {
    bool ok = processGCode(cleaned);
    Serial.println(ok ? F("ok") : F("error"));
    return;
  }

  processManualCommand(cleaned);
}

void processManualCommand(String cmd) {
  if (cmd == "h") {
    confirmManualHome();
    return;
  }

  if (cmd == "?" || cmd == "help") {
    printHelp();
    return;
  }

  if (cmd == "gcode") {
    printGCodeHelp();
    return;
  }

  if (cmd == "p") {
    printPosition();
    return;
  }

  if (cmd == "u") {
    servoPowerOn();
    penUp();
    Serial.println(F("Pen up."));
    return;
  }

  if (cmd == "d") {
    servoPowerOn();
    penDown();
    Serial.println(F("Pen down."));
    return;
  }

  if (cmd == "penoff" || cmd == "soff") {
    servoPowerOff();
    return;
  }

  if (cmd == "penon" || cmd == "son") {
    servoPowerOn();
    return;
  }

  if (cmd == "moff") {
    setMotorsEnabled(false);
    Serial.println(F("Motors disabled."));
    return;
  }

  if (cmd == "mon") {
    setMotorsEnabled(true);
    Serial.println(F("Motors enabled."));
    return;
  }

  if (cmd == "test") {
    servoPowerOn();
    delay(500);
    penUp();
    delay(800);
    penDown();
    delay(800);
    penUp();
    delay(800);
    servoPowerOff();
    return;
  }

  if (cmd.startsWith("accel ")) {
    setAcceleration(cmd.substring(6).toFloat(), true);
    return;
  }

  char type = cmd.charAt(0);

  if (type == 'a') {
    int firstSpace = cmd.indexOf(' ');

    if (firstSpace == -1) {
      Serial.println(F("Bad servo command. Use: a 100"));
      return;
    }

    int angle = cmd.substring(firstSpace + 1).toInt();

    if (angle < 0 || angle > 180) {
      Serial.println(F("Angle blocked. Use 0 to 180."));
      return;
    }

    servoPowerOn();
    penServo.write(angle);
    delay(500);

    Serial.print(F("Servo angle set to "));
    Serial.println(angle);
    return;
  }

  if (type == 'c') {
    int s1 = cmd.indexOf(' ');
    int s2 = cmd.indexOf(' ', s1 + 1);
    int s3 = cmd.indexOf(' ', s2 + 1);

    if (s1 == -1 || s2 == -1 || s3 == -1) {
      Serial.println(F("Bad circle command. Use: c 203 185 40"));
      return;
    }

    float centerX = cmd.substring(s1 + 1, s2).toFloat();
    float centerY = cmd.substring(s2 + 1, s3).toFloat();
    float radius = cmd.substring(s3 + 1).toFloat();

    drawCircle(centerX, centerY, radius, true);
    return;
  }

  if (type == 'r' || type == 'g' || type == 'l') {
    int firstSpace = cmd.indexOf(' ');
    int secondSpace = cmd.indexOf(' ', firstSpace + 1);

    if (firstSpace == -1 || secondSpace == -1) {
      Serial.println(F("Bad command format. Use: r 10 0 or g 50 20 or l 406 370"));
      return;
    }

    float a = cmd.substring(firstSpace + 1, secondSpace).toFloat();
    float b = cmd.substring(secondSpace + 1).toFloat();

    if (type == 'r') {
      moveTo(currentX + a, currentY + b, true);
      return;
    }

    if (type == 'g') {
      moveTo(a, b, true);
      return;
    }

    if (type == 'l') {
      X_MAX = a;
      Y_MAX = b;
      Serial.print(F("Soft limits updated: X_MAX="));
      Serial.print(X_MAX);
      Serial.print(F(" Y_MAX="));
      Serial.println(Y_MAX);
      printPosition();
      return;
    }
  }

  if (type == 's') {
    int firstSpace = cmd.indexOf(' ');

    if (firstSpace == -1) {
      Serial.println(F("Bad speed command. Use: s 1"));
      return;
    }

    setStepDelay(cmd.substring(firstSpace + 1).toInt(), true);
    return;
  }

  Serial.println(F("Unknown command. Send ? for help."));
}

bool processGCode(String line) {
  float value;

  if (getWord(line, 'f', value)) {
    setFeedRate(value, false);
  }

  if (getWord(line, 'g', value)) {
    int code = lround(value);

    if (code == 0 || code == 1) {
      float targetX = currentX;
      float targetY = currentY;

      if (getWord(line, 'x', value)) {
        targetX = value;
      }
      if (getWord(line, 'y', value)) {
        targetY = value;
      }

      if (code == 0) {
        servoPowerOn();
        penUp();
      }

      return moveTo(targetX, targetY, false);
    }

    if (code == 5) {
      float targetX;
      float targetY;
      float control1X;
      float control1Y;
      float control2X;
      float control2Y;

      if (!getWord(line, 'x', targetX) || !getWord(line, 'y', targetY) ||
          !getWord(line, 'i', control1X) || !getWord(line, 'j', control1Y) ||
          !getWord(line, 'p', control2X) || !getWord(line, 'q', control2Y)) {
        Serial.println(F("G5 needs X Y I J P Q for cubic Bezier."));
        return false;
      }

      return bezierTo(control1X, control1Y, control2X, control2Y,
                      targetX, targetY, false);
    }

    if (code == 21) {
      return true;
    }

    if (code == 28) {
      float confirm = 0;
      if (!getWord(line, 'p', confirm) || lround(confirm) != 1) {
        Serial.println(F("G28 needs manual confirmation. Move to bottom-left, then send G28 P1."));
        return false;
      }

      confirmManualHome();
      return true;
    }

    if (code == 90) {
      return true;
    }

    if (code == 91) {
      Serial.println(F("G91 relative mode is not supported yet. Use absolute G90."));
      return false;
    }

    Serial.print(F("Unsupported G-code: G"));
    Serial.println(code);
    return false;
  }

  if (getWord(line, 'm', value)) {
    int code = lround(value);

    if (code == 3) {
      servoPowerOn();
      penDown();
      return true;
    }

    if (code == 5) {
      servoPowerOn();
      penUp();
      return true;
    }

    if (code == 17) {
      setMotorsEnabled(true);
      return true;
    }

    if (code == 18 || code == 84) {
      setMotorsEnabled(false);
      return true;
    }

    if (code == 30 || code == 2) {
      servoPowerOn();
      penUp();
      servoPowerOff();
      return true;
    }

    if (code == 114) {
      printPosition();
      return true;
    }

    if (code == 204) {
      float accel;
      if (!getWord(line, 's', accel)) {
      Serial.println(F("M204 needs S acceleration, example: M204 S10000"));
        return false;
      }

      return setAcceleration(accel, true);
    }

    if (code == 340) {
      bool changed = false;
      float upValue = 0;
      float downValue = 0;
      float liftValue = 0;

      if (getWord(line, 'u', upValue)) {
        if (!setPenDelay('u', lround(upValue), false)) {
          return false;
        }
        changed = true;
      }

      if (getWord(line, 'd', downValue)) {
        if (!setPenDelay('d', lround(downValue), false)) {
          return false;
        }
        changed = true;
      }

      if (getWord(line, 'l', liftValue)) {
        if (!setPenUpLiftPercent(lround(liftValue), false)) {
          return false;
        }
        changed = true;
      }

      if (!changed) {
        Serial.println(F("M340 needs U, D, and/or L, example: M340 U200 D600 L100"));
        return false;
      }

      return true;
    }

    Serial.print(F("Unsupported M-code: M"));
    Serial.println(code);
    return false;
  }

  return true;
}

String stripGCodeComments(String line) {
  int semicolon = line.indexOf(';');
  if (semicolon != -1) {
    line = line.substring(0, semicolon);
  }

  int openParen = line.indexOf('(');
  while (openParen != -1) {
    int closeParen = line.indexOf(')', openParen + 1);
    if (closeParen == -1) {
      line = line.substring(0, openParen);
    } else {
      line = line.substring(0, openParen) + line.substring(closeParen + 1);
    }
    openParen = line.indexOf('(');
  }

  return line;
}

bool pollRealtimeAbort() {
  while (Serial.available()) {
    char c = Serial.read();
    if (c == '!' || c == 24) {
      abortRequested = true;
    }
  }

  return abortRequested;
}

void clearMotionAbort() {
  abortRequested = false;
}

bool getWord(const String &line, char letter, float &value) {
  for (unsigned int i = 0; i < line.length(); i++) {
    if (line.charAt(i) == letter) {
      value = line.substring(i + 1).toFloat();
      return true;
    }
  }

  return false;
}

void confirmManualHome() {
  currentX = 0;
  currentY = 0;
  homeConfirmed = true;
  Serial.println(F("Manual home confirmed. Current position = X0 Y0."));
  printPosition();
}

void printHelp() {
  Serial.println();
  Serial.println(F("CoreXY pen plotter manual control ready."));
  Serial.println();
  Serial.println(F("Coordinate system:"));
  Serial.println(F("  X0 Y0     = bottom-left manual home"));
  Serial.println(F("  X203 Y185 = center"));
  Serial.println(F("  X406 Y370 = far corner"));
  Serial.println();
  Serial.println(F("Manual homing:"));
  Serial.println(F("  1. Type moff to release motors, if needed."));
  Serial.println(F("  2. Push gantry/toolhead to bottom-left home."));
  Serial.println(F("  3. Type mon to enable motors."));
  Serial.println(F("  4. Type h to set X0 Y0."));
  Serial.println();
  Serial.println(F("Manual commands:"));
  Serial.println(F("  ?              = show this help"));
  Serial.println(F("  gcode          = show supported G-code"));
  Serial.println(F("  h              = confirm manual home as X0 Y0"));
  Serial.println(F("  !              = realtime abort current motion"));
  Serial.println(F("  p              = print current position"));
  Serial.println(F("  r dx dy         = relative move in mm"));
  Serial.println(F("  g x y           = absolute move in mm"));
  Serial.println(F("  c x y radius    = draw circle"));
  Serial.println(F("  l xmax ymax     = set soft limits"));
  Serial.println(F("  s fastDelay     = set step delay, 1 or higher"));
  Serial.println(F("  accel n         = set accel in steps/sec^2"));
  Serial.println(F("  mon / moff      = enable / disable motors"));
  Serial.println(F("  son / soff      = servo power on / off"));
  Serial.println(F("  u / d           = pen up / pen down"));
  Serial.println(F("  a angle         = servo angle"));
  Serial.println(F("  test            = servo power movement test"));
  Serial.println();
}

void printGCodeHelp() {
  Serial.println();
  Serial.println(F("Supported plotter G-code:"));
  Serial.println(F("  G21             = millimeters"));
  Serial.println(F("  G90             = absolute coordinates"));
  Serial.println(F("  G28 P1          = confirm manual home at X0 Y0"));
  Serial.println(F("  G0 Xnnn Ynnn    = travel move, pen up"));
  Serial.println(F("  G1 Xnnn Ynnn Ff = drawing/feed move"));
  Serial.println(F("  G5 X Y I J P Q  = cubic Bezier, absolute controls"));
  Serial.println(F("  M204 Snnn       = set accel in steps/sec^2"));
  Serial.println(F("  M340 Ummm Dmmm Lpct = set pen delays and up lift percent"));
  Serial.println(F("  M3              = pen down"));
  Serial.println(F("  M5              = pen up"));
  Serial.println(F("  M17             = motors enabled"));
  Serial.println(F("  M18 / M84       = motors disabled"));
  Serial.println(F("  M114            = report position"));
  Serial.println(F("  M2 / M30        = end program, pen up and servo off"));
  Serial.println();
}

void printPosition() {
  Serial.print(F("Position: X="));
  Serial.print(currentX);
  Serial.print(F(" Y="));
  Serial.print(currentY);
  Serial.print(F(" | Limits: X_MAX="));
  Serial.print(X_MAX);
  Serial.print(F(" Y_MAX="));
  Serial.print(Y_MAX);
  Serial.print(F(" | fastDelay="));
  Serial.print(fastDelay);
  Serial.print(F(" | accel="));
  Serial.print(accelStepsPerSecond2);
  Serial.print(F(" | penUpDelay="));
  Serial.print(penUpDelay);
  Serial.print(F(" | penDownDelay="));
  Serial.print(penDownDelay);
  Serial.print(F(" | penUpLift="));
  Serial.print(penUpLiftPercent);
  Serial.print(F("%"));
  Serial.print(F(" | home="));
  Serial.print(homeConfirmed ? F("YES") : F("NO"));
  Serial.print(F(" | motors="));
  Serial.print(motorsEnabled ? F("ON") : F("OFF"));
  Serial.print(F(" | servoPower="));
  Serial.println(servoPowered ? F("ON") : F("OFF"));
}

void setMotorsEnabled(bool enabled) {
  digitalWrite(EN_PIN, enabled ? LOW : HIGH);
  motorsEnabled = enabled;
}

void servoPowerOn() {
  if (servoPowered) {
    return;
  }

  Serial.println(F("Turning servo power ON..."));

  penServo.write(effectivePenUpAngle());
  penServo.attach(SERVO_PIN);
  delay(100);

  digitalWrite(SERVO_POWER_PIN, HIGH);
  servoPowered = true;

  delay(500);
  penServo.write(effectivePenUpAngle());
  delay(penUpDelay);

  Serial.println(F("Servo power ON."));
}

void servoPowerOff() {
  if (!servoPowered) {
    Serial.println(F("Servo power already OFF."));
    return;
  }

  Serial.println(F("Turning servo power OFF..."));

  penServo.write(PEN_UP);
  delay(penUpDelay);

  digitalWrite(SERVO_POWER_PIN, LOW);
  servoPowered = false;

  delay(200);
  penServo.detach();

  Serial.println(F("Servo power OFF."));
}

void penUp() {
  penServo.write(effectivePenUpAngle());
  delay(penUpDelay);
}

void penDown() {
  penServo.write(PEN_DOWN);
  delay(penDownDelay);
}

int effectivePenUpAngle() {
  long span = long(PEN_UP) - long(PEN_DOWN);
  return int(long(PEN_DOWN) + (span * long(penUpLiftPercent)) / 100L);
}

bool setPenDelay(char which, int newDelay, bool report) {
  if (newDelay < 0 || newDelay > 2000) {
    if (report) {
      Serial.println(F("Pen delay blocked. Use 0 to 2000 ms."));
    }
    return false;
  }

  if (which == 'u') {
    penUpDelay = newDelay;
  } else if (which == 'd') {
    penDownDelay = newDelay;
  } else {
    return false;
  }

  if (report) {
    Serial.print(F("Pen delays updated. up="));
    Serial.print(penUpDelay);
    Serial.print(F(" down="));
    Serial.println(penDownDelay);
  }

  return true;
}

bool setPenUpLiftPercent(int newPercent, bool report) {
  if (newPercent < 0 || newPercent > 100) {
    if (report) {
      Serial.println(F("Pen lift blocked. Use 0 to 100 percent."));
    }
    return false;
  }

  penUpLiftPercent = newPercent;

  if (report) {
    Serial.print(F("Pen up lift updated. lift="));
    Serial.print(penUpLiftPercent);
    Serial.println(F("%"));
  }

  return true;
}

bool drawCircle(float centerX, float centerY, float radius, bool report) {
  if (radius <= 0) {
    Serial.println(F("Circle blocked. Radius must be positive."));
    return false;
  }

  if (centerX - radius < 0 || centerX + radius > X_MAX ||
      centerY - radius < 0 || centerY + radius > Y_MAX) {
    Serial.println(F("Circle blocked by soft limits."));
    Serial.print(F("Circle needs X="));
    Serial.print(centerX - radius);
    Serial.print(F(" to "));
    Serial.print(centerX + radius);
    Serial.print(F(" | Y="));
    Serial.print(centerY - radius);
    Serial.print(F(" to "));
    Serial.println(centerY + radius);
    printPosition();
    return false;
  }

  const int segments = 72;
  const float FULL_CIRCLE = 6.28318530718;

  if (report) {
    Serial.print(F("Drawing circle: center X="));
    Serial.print(centerX);
    Serial.print(F(" Y="));
    Serial.print(centerY);
    Serial.print(F(" radius="));
    Serial.println(radius);
  }

  servoPowerOn();
  penUp();
  if (!moveTo(centerX + radius, centerY, report)) {
    return false;
  }
  penDown();

  for (int i = 1; i <= segments; i++) {
    float angle = FULL_CIRCLE * i / segments;
    float x = centerX + radius * cos(angle);
    float y = centerY + radius * sin(angle);

    if (!moveTo(x, y, report)) {
      penUp();
      return false;
    }
  }

  penUp();

  if (report) {
    Serial.println(F("Circle done."));
  }

  return true;
}

bool moveTo(float targetX, float targetY, bool report) {
  if (!homeConfirmed) {
    Serial.println(F("Move blocked. Manually home first, then send h or G28 P1."));
    return false;
  }

  if (!motorsEnabled) {
    Serial.println(F("Move blocked. Motors are disabled. Send mon or M17."));
    return false;
  }

  if (targetX < 0 || targetX > X_MAX || targetY < 0 || targetY > Y_MAX) {
    Serial.println(F("Move blocked by soft limits."));
    Serial.print(F("Requested: X="));
    Serial.print(targetX);
    Serial.print(F(" Y="));
    Serial.println(targetY);
    printPosition();
    return false;
  }

  long aSteps;
  long bSteps;
  coreXYStepsBetween(currentX, currentY, targetX, targetY, aSteps, bSteps);
  long totalSteps = maxCoreXYSteps(aSteps, bSteps);
  float startX = currentX;
  float startY = currentY;

  if (report) {
    Serial.print(F("Moving to X="));
    Serial.print(targetX);
    Serial.print(F(" Y="));
    Serial.println(targetY);
  }

  long completedSteps = stepCoreXY(aSteps, bSteps);

  if (abortRequested || completedSteps < totalSteps) {
    float fraction = totalSteps > 0 ? (float)completedSteps / (float)totalSteps : 1.0;
    currentX = startX + (targetX - startX) * fraction;
    currentY = startY + (targetY - startY) * fraction;
    Serial.println(F("Move aborted."));
    printPosition();
    return false;
  }

  currentX = targetX;
  currentY = targetY;

  if (report) {
    printPosition();
  }

  return true;
}
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

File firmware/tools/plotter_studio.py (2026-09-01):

#!/usr/bin/env python3
"""Local browser app for slicing and controlling the CoreXY pen plotter."""

from __future__ import annotations

import math
import base64
import html
import io
import re
import subprocess
import sys
import threading
import time
import uuid
from collections import deque
from pathlib import Path
from typing import Any

try:
    from PIL import Image, ImageFilter, ImageOps
    import cv2
    import numpy as np
    from scipy import ndimage
    import serial
    from fastapi import FastAPI, HTTPException
    from fastapi.responses import FileResponse
    from fastapi.staticfiles import StaticFiles
    from pydantic import BaseModel, Field
    from serial.tools import list_ports
    from svgpathtools import Arc, CubicBezier, Line, QuadraticBezier, svg2paths2
except ImportError:
    print(
        "Missing app dependencies. Run:\n"
        "  python3 -m venv .venv\n"
        "  .venv/bin/python -m pip install -r tools/requirements.txt",
        file=sys.stderr,
    )
    raise SystemExit(2)


ROOT = Path(__file__).resolve().parents[1]
STATIC_DIR = ROOT / "app" / "static"
DATA_DIR = ROOT / ".plotter-app"
UPLOAD_DIR = DATA_DIR / "uploads"

BAUD = 115200
X_MAX = 406.0
Y_MAX = 370.0
STEPS_PER_MM = 160.0
LETTER_PAPER_WIDTH = 140.0
LETTER_PAPER_HEIGHT = round(LETTER_PAPER_WIDTH * 8.5 / 11.0, 3)
RASTER_TRACE_MAX_SIDE = 3200
trace_lock = threading.Lock()
trace_generation = 0
trace_jobs: dict[str, dict[str, Any]] = {}


class TraceCanceled(Exception):
    pass


class SliceSettings(BaseModel):
    x_max: float = Field(default=X_MAX, gt=0)
    y_max: float = Field(default=Y_MAX, gt=0)
    paper_mode: str = "full"
    margin: float = Field(default=12.0, ge=0)
    fit_to_bed: bool = True
    scale: float = Field(default=1.0, gt=0)
    scale_x: float | None = Field(default=None, gt=0)
    scale_y: float | None = Field(default=None, gt=0)
    offset_x: float = 0.0
    offset_y: float = 0.0
    rotation: float = 0.0
    speed_delay: int = Field(default=50, ge=1, le=200)
    accel: float = Field(default=10000.0, ge=8000, le=100000)
    pen_up_delay: int = Field(default=200, ge=0, le=2000)
    pen_down_delay: int = Field(default=600, ge=0, le=2000)
    pen_up_lift_percent: int = Field(default=100, ge=0, le=100)
    sample_mm: float = Field(default=1.0, gt=0)


class SliceRequest(BaseModel):
    filename: str = "drawing.svg"
    svg_text: str
    settings: SliceSettings = SliceSettings()


class ConnectRequest(BaseModel):
    port: str | None = None
    baud: int = BAUD


class ManualCommandRequest(BaseModel):
    command: str


class JogRequest(BaseModel):
    dx: float = 0.0
    dy: float = 0.0


class StartJobRequest(BaseModel):
    gcode: str
    confirm_home: bool = False
    name: str = "plate.gcode"


class SettingsRequest(BaseModel):
    speed_delay: int | None = Field(default=None, ge=1, le=200)
    accel: float | None = Field(default=None, ge=8000, le=100000)
    pen_up_delay: int | None = Field(default=None, ge=0, le=2000)
    pen_down_delay: int | None = Field(default=None, ge=0, le=2000)
    pen_up_lift_percent: int | None = Field(default=None, ge=0, le=100)


class RasterTraceRequest(BaseModel):
    filename: str = "image.png"
    image_data: str
    trace_mode: str = "contour"
    threshold: int = Field(default=34, ge=1, le=255)
    simplify_px: float = Field(default=1.5, ge=0, le=32)
    max_side: int = Field(default=720, ge=64, le=RASTER_TRACE_MAX_SIDE)
    min_path_px: float = Field(default=8.0, ge=0, le=200)
    link_gap_px: float = Field(default=5.0, ge=0, le=80)


def safe_name(name: str) -> str:
    clean = re.sub(r"[^A-Za-z0-9_.-]+", "_", Path(name).name)
    return clean or "drawing.svg"


def paper_area_for_settings(settings: SliceSettings) -> dict[str, Any]:
    mode = settings.paper_mode.strip().lower()
    if mode == "letter":
        width = min(LETTER_PAPER_WIDTH, settings.x_max)
        height = min(LETTER_PAPER_HEIGHT, settings.y_max)
        x_min = (settings.x_max - width) / 2.0
        y_min = (settings.y_max - height) / 2.0
        label = "Letter"
    else:
        mode = "full"
        width = settings.x_max
        height = settings.y_max
        x_min = 0.0
        y_min = 0.0
        label = "Full canvas"

    return {
        "mode": mode,
        "label": label,
        "x_min": round(x_min, 3),
        "x_max": round(x_min + width, 3),
        "y_min": round(y_min, 3),
        "y_max": round(y_min + height, 3),
        "width": round(width, 3),
        "height": round(height, 3),
        "center_x": round(x_min + width / 2.0, 3),
        "center_y": round(y_min + height / 2.0, 3),
    }


def next_trace_token() -> int:
    global trace_generation
    with trace_lock:
        trace_generation += 1
        return trace_generation


def check_trace_deadline(deadline: float | int) -> None:
    if isinstance(deadline, int):
        with trace_lock:
            if deadline != trace_generation:
                raise TraceCanceled("Trace canceled.")


def start_trace_job(request: RasterTraceRequest) -> dict[str, str]:
    job_id = uuid.uuid4().hex
    token = next_trace_token()
    with trace_lock:
        trace_jobs[job_id] = {
            "status": "running",
            "progress": 2,
            "label": "Queued",
            "created_at": time.monotonic(),
            "token": token,
        }

    thread = threading.Thread(target=run_trace_job, args=(job_id, token, request), daemon=True)
    thread.start()
    return {"job_id": job_id}


def cancel_all_trace_jobs() -> dict[str, Any]:
    global trace_generation
    with trace_lock:
        trace_generation += 1
        canceled = 0
        for job in trace_jobs.values():
            if job.get("status") == "running":
                job.update({"status": "canceled", "progress": 0, "label": "Trace canceled"})
                canceled += 1
        return {"status": "canceled", "canceled": canceled}


def trace_job_progress(job_id: str, progress: float, label: str) -> None:
    with trace_lock:
        job = trace_jobs.get(job_id)
        if not job or job.get("status") != "running":
            return
        job["progress"] = max(job.get("progress", 0), min(96, progress))
        job["label"] = label
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

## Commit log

2026-08-10 Add cleaned Onshape BOM
    [bom.csv]
2026-08-10 Clean up BOM document by removing excess text
    Removed unnecessary introductory text and source section from the BOM.
2026-08-30 Package plotter firmware and studio app
    [bom.csv]
2026-08-30 Organize shipping files
    [0.5-mm-Spacer-for-Y-Cart.stl, 1-mm-Spacer-for-Y-Cart.stl, 1.5-mm-M-U-Spacer-for-Corner-Brackets.stl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]
2026-08-31 Prepare shipping docs and media
    [bom.csv]
2026-08-31 Restructure BOM purchase links
2026-08-31 Add STEP exports and CSV BOM
    [0.5-mm-Spacer-for-Y-Cart.step, 1-mm-Spacer-for-Y-Cart.step, 1.5-mm-M+U-Spacer-for-Corner-Brackets.step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]
2026-08-31 Polish assembly guide
2026-09-01 Update project story and BOM cost range
